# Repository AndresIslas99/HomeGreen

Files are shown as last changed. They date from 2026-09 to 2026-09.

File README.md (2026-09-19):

# HomeGreen — Huerto comercial automatizado en CDMX

**Guía-brújula, nivel wiki, para construir y operar un huerto comercial de microgreens y
hierbas NFT en un patio de 80 m² en la Ciudad de México**, automatizado con ESP32 + ESPHome +
Home Assistant, por fases y financiado con ventas. Todo lo que hay aquí es accionable: qué
comprar (con enlace y precio verificado), cómo instalarlo (con diagramas eléctricos,
hidráulicos y CAD), cómo operarlo (guías paso a paso), cómo validar cada avance (métodos
V1–V11 y gates), y el firmware listo para flashear.

> **Sitio web de la wiki:** https://andresislas99.github.io/HomeGreen/ — se publica solo desde
> `main` con GitHub Actions ([`.github/workflows/docs.yml`](.github/workflows/docs.yml)).
> La primera vez: *Settings → Pages → Source: GitHub Actions*. Para verla en local:
> `pip install mkdocs-material mkdocs-glightbox && mkdocs serve`.

## Empieza aquí (en este orden)

1. **[Antes de gastar un peso](docs/empieza-aqui/antes-de-gastar-un-peso.md)** — la semana 0:
   escritura/condominio, contador (¿eres socio de alguna empresa?), consumo eléctrico, tandeo y
   agua de tu llave, aviso de huerto, curso gratis. Cuesta $0–740 y evita los errores caros.
2. **[Cómo usar esta guía](docs/empieza-aqui/como-usar-esta-guia.md)** — convenciones, cómo
   marcar tu avance, cómo funcionan los gates.
3. **[Línea de tiempo](docs/empieza-aqui/linea-de-tiempo.md)** — 40 semanas con hitos, gates y
   calendario de riesgos climáticos.
4. **[Fase 0 · Validación comercial](docs/fases/fase-0/index.md)** — rack, 20 charolas, dos
   clientes recurrentes en 6 semanas. Si no se logra, perdiste ~$6k y comes microgreens.

## Mapa del proyecto

| Fase | Qué | Cuándo | Inversión (MXN) | Gate para pasar |
|---|---|---|---|---|
| [0 · Validación comercial](docs/fases/fase-0/index.md) | Rack bajo techo, microgreens, vender a chefs | Semanas 1–6 | $8,814 | ≥2 clientes con 3 compras semanales seguidas, margen ≥55 % |
| [1 · Túnel + automatización v1](docs/fases/fase-1/index.md) | Túnel PTR 3×6 m, tinaco + captación pluvial, nodo ESP32 de riego/ambiente | Meses 2–4 | $41,634 | 4–5 clientes fijos, demanda insatisfecha, v1 estable 30 días |
| [2 · NFT + automatización v2](docs/fases/fase-2/index.md) | Túnel 5×6 m, 8 líneas NFT, pH/EC, respaldo DC-first, cadena de frío | Meses 5–9 | $27,251 | Neto ≥$12k/mes × 3 meses con ≤9 h/semana medidas |
| [3 · Consolidación](docs/fases/fase-3/index.md) | Camas elevadas, gantry/visión, testbed agtech | Mes 10+ | discrecional | — |

> **Los montos salen de [`bom/partidas.csv`](bom/partidas.csv)** y los calcula
> [`tools/gen_bom.py`](tools/gen_bom.py), que falla si alguna fila no multiplica. El acumulado de
> las tres fases es **$77,699**, no los ~$86,500 que se publicaban antes: la diferencia es que el
> total viejo cobraba dos veces la partida de seguridad eléctrica y el no-break, y sumaba
> alternativas entre las que hay que elegir una. No se recortó nada del alcance; ver
> [BOM por fase](docs/referencia/bom.md).
>
> La Fase 1 sube y la Fase 2 baja porque el GFCI, la tierra física y el electricista ($4,559)
> estaban presupuestados en las dos, y el proyecto los exige en la S13 de la Fase 1.

## Qué contiene la wiki

| Sección | Para qué |
|---|---|
| [Fases](docs/fases/fase-0/index.md) | Por cada fase: compras exactas, montaje, operación, ventas y gate — con "cómo se verá" (planta + render 3D) |
| [Guías](docs/guias/sembrar-una-charola.md) | Una tarea = una página: sembrar, sanitizar semilla, armar línea NFT, calibrar sondas, instalar GFCI y tierra, flashear ESPHome, visitar a un chef, facturar, cobrar… |
| [Diseño](docs/diseno/index.md) | Arquitectura del sistema: [eléctrico](docs/diseno/electrico.md) (esquemas + pines), [hidráulico](docs/diseno/hidraulico.md) (P&ID), [control](docs/diseno/control.md) (lazos e histéresis), [datos](docs/diseno/datos.md), [layout del patio](docs/diseno/layout-patio.md), [estructura del túnel](docs/diseno/estructura-tunel.md) (CAD) |
| [Validación](docs/validacion/index.md) | Lazos L0–L4, métodos V1–V11 con checklists imprimibles, [KPIs](docs/validacion/kpis.md) y [gates](docs/validacion/gates.md) |
| [Software](docs/software/index.md) | [Firmware ESPHome](docs/software/firmware.md), [Home Assistant](docs/software/home-assistant.md) (automatizaciones y dashboard), [herramientas CLI](docs/software/herramientas-cli.md) |
| [Aprendizaje](docs/aprendizaje/videos.md) | Videos verificados (incrustados), libros y cursos por fase |
| [Referencia](docs/referencia/bom.md) | BOM por fase, normativa, clima, glosario, FAQ, [verificación de enlaces](docs/referencia/enlaces.md), los 9 documentos base y los 17 informes de investigación |

## Archivos que no son documentación

```
firmware/esphome/        nodo-riego-v1.yaml · nodo-ambiente.yaml · nodo-nft-v2.yaml (listos para ESPHome)
firmware/homeassistant/  automations.yaml · dashboard-huerto.yaml · configuration-snippets.yaml
hardware/electrico/      scripts schemdraw que generan los esquemas eléctricos (SVG)
hardware/cad/            modelos OpenSCAD paramétricos (túnel, rack, línea NFT, patio) + renders
hardware/hidraulico/     generador de diagramas P&ID
bom/                     listas de materiales por fase (CSV con enlace y estado del precio)
bitacora/                plantillas CSV (producción, ventas, cobranza, costos, timesheet) + datos de ejemplo
tools/                   check_links.py · kpis.py · informe_semanal.py · gate_audit.py (Python 3.11, sin dependencias)
.github/workflows/       docs.yml (publica la wiki) · links.yml (verifica enlaces cada lunes)
docs/assets/diagramas/   SVG eléctricos, hidráulicos, plantas, animaciones; PNG de CAD
```

## Los 6 números que cambiaron el plan original

1. La bomba periférica de 0.5 HP consumía ~324 kWh/mes → tarifa DAC (~$2,600/mes). Se rediseñó a
   **bomba 12 V DC colgada de una batería LiFePO4** (DC-first): ~32 kWh/mes y un apagón no mata el NFT.
2. **PVC sanitario** 4" ($415/tramo), no cédula 40 ($1,401): el NFT corre sin presión.
3. Precios de venta corregidos con mercado real: **charola viva $90–120**, clamshell $50–90/100 g.
4. **El chícharo con semilla a $340/kg pierde dinero** (275 g/charola): requiere arvejón de CEDA.
5. Racks reales cuestan **$2,000–2,600**; "Hunab" no existe (es Hanlob y no vende antigranizo).
6. **Neto realista $6,500–11,000/mes** con merma, enero −35 %, CAC recurrente y 15 h/semana reales.
7. **UNIT Electronics tiene mostrador en Av. Copilco 357, Coyoacán** — el resto de la wiki lo
   trataba como proveedor solo en línea. Cubre casi todo el BOM de automatización, y ahí el
   sensor SHT41 cuesta **$91** contra los $300 del SHT31 que traía el BOM. La ruta de compra
   presencial completa está en [Proveedores presenciales](docs/referencia/proveedores-presenciales.md).

## Filosofía

1. **Vender antes de construir** — cada fase se financia con la anterior; los gates se escriben
   y se versionan antes de gastar.
2. **Fail-safe físico, no de software** — la bomba NFT cuelga del bus de batería; Home Assistant
   avisa y optimiza, pero el agua nunca depende de que esté vivo.
3. **Todo desde el tinaco, nunca de la toma** — CDMX tiene tandeo.
4. **Operación como sistema de control** — todo se mide y se registra; un lazo agéntico semanal
   (LLM sobre la bitácora y Home Assistant) convierte los datos en decisiones.

## Contribuir

Los precios caducan: si encuentras uno distinto, corrige la fila en `bom/*.csv` o en
`docs/referencia/01-proveedores-cdmx.md` con la fecha y abre un PR.

Dos comprobaciones corren solas y conviene correrlas antes de abrir el PR:

```bash
mkdocs build --strict        # falla con cualquier enlace interno, ancla o imagen rota
python3 tools/check_links.py # verifica los ~680 enlaces externos
```

`--strict` valida las 112 páginas: enlaces relativos, anclas, imágenes y que no haya páginas
fuera del `nav`. `check_links.py` corre cada lunes (workflow `links.yml`) y **solo falla con un
enlace muerto nuevo**: los ya conocidos y anotados viven en
[`tools/enlaces-muertos-conocidos.txt`](tools/enlaces-muertos-conocidos.txt), así un `dead`
nuevo —una partida del BOM que ya no se puede comprar— no se pierde entre el ruido viejo.

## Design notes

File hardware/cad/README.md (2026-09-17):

# Modelos CAD paramétricos (OpenSCAD)

Modelos 3D del huerto en OpenSCAD (software libre; probados con la versión 2021.01).
Cada archivo es un modelo paramétrico: cambias un número al principio del archivo, vuelves a
renderizar y el PNG de la wiki se actualiza. Los renders viven en
`docs/assets/diagramas/cad/` y los usan las páginas de diseño
(`docs/diseno/estructura-tunel.md`, `rack-y-charolas.md`, `layout-patio.md`) y los índices
de fase.

| Archivo | Qué modela | Render (docs/assets/diagramas/cad/) | Fase |
|---|---|---|---|
| `tunel_3x6.scad` | Túnel a dos aguas 3 × 6 m: PTR 1½" cal. 14, 6 columnas, placas base 100 × 100 mm con 4 anclas 3/8" × 5", pendiente 30 %, largueros, contravientos, plástico translúcido, malla antigranizo a 150 mm, canalón + bajante. Imprime la **lista de cortes** en consola. | `tunel-3x6.png` | 1 |
| `tunel_5x6.scad` | El mismo módulo `tunel()` con `ancho = 5000`, 4 pórticos (8 columnas) y 2 largueros de techo por agua. No copia geometría: hace `use <tunel_3x6.scad>`. | `tunel-5x6.png` | 2 |
| `rack_charolas.scad` | Rack Husky 1830 × 914 × 457 mm, 5 niveles, 3 charolas 1020 (254 × 508 × 60 mm) por nivel, 2 tubos T8 de 1200 mm por nivel iluminado, riser de riego. Los niveles muestran los estados del SOP (tapada / brote / desarrollo / cosecha). | `rack-charolas.png` | 0–1 |
| `linea_nft.scad` | Línea NFT: PVC sanitario 4" (OD 114 mm) × 3000 mm, 10 perforaciones a 200 mm entre centros, canastillas 3", pendiente 2.5 %, 3 soportes de PTR 1", tapas, entrada ½" y retorno 2". Incluye el módulo `bancada_nft()` (n líneas sobre soportes compartidos). | `linea-nft.png` | 2 |
| `patio_fase2.scad` | Composición del patio de 10 × 8 m (supuesto): túnel 5 × 6, 8 líneas NFT en 2 bancadas, tambo 200 L, tinaco 750 L, 3 racks, gabinetes IP65, zona de cosecha. Usa los tres archivos anteriores con `use <...>`. | `patio-fase-2-3d.png` | 2 |

Unidades: **milímetros**. Ejes: X = oeste → este, Y = sur → norte, Z = altura. En el túnel la
cumbrera corre a lo largo de Y y la puerta va en la cabecera norte (`y = largo`), porque la
wiki supone el acceso del patio al norte.

## Requisitos

- OpenSCAD 2021.01 o posterior (`sudo apt install openscad` en Debian/Ubuntu; en macOS `brew
  install --cask openscad`; en Windows el instalador oficial).
- Para renderizar sin pantalla (servidor, CI): `xvfb-run` (`sudo apt install xvfb`).
- Fuente DejaVu Sans para los rótulos (viene en casi todas las distribuciones; si falta, el
  rótulo sale con la fuente por defecto y no pasa nada).

## Cómo modificar parámetros

1. Abre el `.scad` en el editor de OpenSCAD (o cualquier editor de texto).
2. Todos los parámetros están **al principio del archivo**, agrupados y comentados en español
   (geometría, perfiles, placa y anclas, cubierta, canalón, "qué dibujar", colores).
3. Cambia el valor, guarda y pulsa F5 (preview). La consola imprime la lista de cortes / el
   resumen con los nuevos valores.

Ejemplos útiles:

| Quiero… | Cambia… |
|---|---|
| Un túnel de 4 × 7 m | En `tunel_3x6.scad`: `ancho = 4000; largo = 7000;` (o crea un `tunel_4x7.scad` con `use <tunel_3x6.scad>` como hace `tunel_5x6.scad`). |
| Postes cada 2 m en vez de 3 m | `n_porticos = 4` (8 columnas, 32 anclas). |
| Alero a 2.2 m | `h_columna = 2200`. |
| Pendiente de 25 % (mínimo) | `pendiente = 25`. No bajes de 25 %: el granizo acumulado es la causa #1 de colapso del plástico. |
| Malla antigranizo a 100 mm del plástico | `sep_malla = 100` (el informe admite 10–20 cm). |
| Ver solo el esqueleto (sin plástico ni malla) | `mostrar_plastico = false; mostrar_malla = false;` |
| Bajante del canalón en el alero oeste | `lado_bajante = -1`. |
| Cortinas laterales dibujadas abiertas | Hoy se dibujan cerradas; pon `mostrar_plastico = false` o edita la altura del `cube` de "cortinas laterales" en `tunel()`. |
| Rack de 1.22 m de ancho (Husky ancho) | En `rack_charolas.scad`: `rack_ancho = 1219; rack_fondo = 610; charolas_por_nivel = 4;` |
| Charolas 1020 sin sobresalir del fondo | Solo con el rack de 610 mm de fondo (arriba); con 457 mm la charola de 508 sobresale 25 mm por lado, es normal. |
| Cilantro a 15 cm en el NFT | En `linea_nft.scad`: `sep_perf = 150; n_plantas = 14;` (14 × 150 = 2.1 m centrados en 3 m). |
| Perforación para la canastilla que compré | `d_perf = <lo que mediste en el cuerpo bajo el labio>` y `canastilla_cuerpo` igual. **El diámetro real se mide en la canastilla, nunca se toma de aquí.** |
| Pendiente NFT de 3 % | `pendiente = 3` (en `linea_nft.scad`). |
| Bancada de 3 líneas | En `patio_fase2.scad`: `nft_lineas_por_bancada = 3`. |
| Patio de 12 × 7 m | En `patio_fase2.scad`: `patio_x = 12000; patio_y = 7000;` y reacomoda `tunel_cx`, `tunel_y0`, `tinaco_pos`, `racks`. |

Las funciones y módulos se reutilizan entre archivos con `use <archivo.scad>`; `use` importa
módulos y funciones (con sus valores por defecto) pero **no** las variables de nivel superior:
por eso `tunel_5x6.scad` vuelve a declarar `ancho`, `largo`, etc. y los pasa como argumentos.

## Cómo re-renderizar los PNG de la wiki

Desde `hardware/cad/` (las rutas de salida son relativas a esa carpeta). Con pantalla, quita
`xvfb-run -a`.

```bash
cd hardware/cad
OUT=../../docs/assets/diagramas/cad
OPTS="--autocenter --viewall --imgsize=1400,1000 --projection=p --colorscheme=Tomorrow"

xvfb-run -a openscad -o $OUT/tunel-3x6.png       $OPTS --camera=0,0,0,62,0,212,0 tunel_3x6.scad
xvfb-run -a openscad -o $OUT/tunel-5x6.png       $OPTS --camera=0,0,0,62,0,212,0 tunel_5x6.scad
xvfb-run -a openscad -o $OUT/rack-charolas.png   $OPTS --camera=0,0,0,72,0,22,0  rack_charolas.scad
xvfb-run -a openscad -o $OUT/linea-nft.png       $OPTS --camera=0,0,0,52,0,25,0  linea_nft.scad
xvfb-run -a openscad -o $OUT/patio-fase-2-3d.png $OPTS --camera=0,0,0,42,0,200,0 patio_fase2.scad
```

- `--camera=tx,ty,tz,rx,ry,rz,dist` es la cámara "gimbal": con `--viewall` la distancia se
  ajusta sola y solo importan `rx` (elevación: 90 = de frente, 0 = desde arriba) y `rz`
  (azimut: 0 = desde el sur, 180–215 = desde el norte/noreste, donde está la puerta).
- Si un render sale vacío o cortado, cambia `rz`/`rx` o sube `dist` quitando `--viewall`.
- Cada PNG de la wiki pesa entre 48 y 230 KB; si uno sale de menos de 20 KB, el modelo no se
  dibujó (revisa errores de sintaxis en la consola: `openscad -o x.png archivo.scad 2>&1`).
- Los `ECHO` (lista de cortes, resumen de rack/línea) salen por **stdout**: para guardarlos,
  `openscad -o /tmp/x.png tunel_3x6.scad > cortes.txt 2>&1`.

## Cómo leer la lista de cortes del túnel

`tunel_3x6.scad` y `tunel_5x6.scad` imprimen tres bloques:

1. `PERFIL | pieza | cantidad × longitud` (longitudes de eje a eje; los cabios llevan un
   perfil extra de traslape).
2. Metros lineales por perfil y el **mínimo teórico** de tramos (metros ÷ 6), que **no**
   incluye el desperdicio de corte.
3. Los **tramos reales** que hay que comprar: el modelo empaqueta las piezas en tramos por
   *primer ajuste decreciente* (FFD) con 3 mm de kerf por corte, y lo imprime para tramos
   de 6.00 m y de 6.10 m (el PTR llega en 6.0–6.10 m según el proveedor), con el detalle
   de qué piezas salen de cada tramo. Ejemplo (túnel 3 × 6 m):

   ```
   ECHO: "PTR 1 1/2: tramos REALES de 6 m (FFD, kerf 3 mm): 11 -> [[6000], [6000], [6000], [2924, 2924], [2924, 2450, 412], [2000, 2000, 1586], ...]"
   ECHO: "PTR 1 1/2: tramos REALES de 6.1 m (FFD, kerf 3 mm): 10 -> ..."
   ```

   Es una cota práctica y reproducible, no la óptima: dásela al herrero como punto de
   partida. Truco: tres columnas de 2.00 m no caben en un tramo de 6.00 m exactos
   (6,000 + 2 cortes); si tu proveedor entrega 6.10 m sí caben, y si no, corta las columnas
   a 1.99 m. Para otro largo de tramo o de kerf: `lista_cortes(L_tramo = 6100, kerf = 2)`.
   La función `empaquetar(longitudes, L_tramo, kerf)` sirve para cualquier lista de cortes
   (p. ej. los soportes de PTR 1" del NFT).

## Exportar a STL / DXF (opcional)

```bash
openscad -o tunel_3x6.stl tunel_3x6.scad   # malla 3D (los .stl están en .gitignore)
openscad -o placa.dxf placa_2d.scad         # plano 2D: solo si creas un archivo con projection()
```

Para planos 2D de las placas base o de las perforaciones del NFT, lo más simple es un archivo
nuevo con `projection()` sobre el módulo que quieras y exportar a DXF/SVG.

## Limitaciones honestas

- Es un modelo **geométrico** para dimensionar, cortar y explicar; **no es un cálculo
  estructural**. Las cargas de viento y el margen de las anclas se discuten con cifras del
  informe en `docs/diseno/estructura-tunel.md`; para una estructura mayor de 30 m² o en azotea,
  consulta a un ingeniero.
- Las uniones se dibujan a tope (sin cartabones ni cordones de soldadura); el herrero decide
  el detalle de unión y puede pedir 1–2 cm extra por pieza para escuadrar.
- En el preview (F5/OpenCSG) lo que se dibuja después de una superficie translúcida queda
  oculto tras ella: por eso en `patio_fase2.scad` el túnel y las bardas van al final. Si
  agregas objetos dentro del túnel, agrégalos **antes** del bloque "Superficies translúcidas".
- Las dimensiones del tinaco de 750 L y del tambo de 200 L son típicas, no de ficha técnica:
  mide el que compres antes de trazar bases.

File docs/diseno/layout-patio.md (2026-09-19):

# Layout del patio por fase

**En una línea:** dónde va cada cosa en los 80 m² —racks, túnel, tinaco, tambo NFT, gabinetes, cuarto de cosecha, camas— y por dónde corren el agua y la electricidad, fase por fase, para que replantees el patio real en una mañana con hilo, cinta y escuadra.

!!! info "Qué decide esta página"
    - **La posición de cada elemento** en las cuatro plantas (Fase 0 → 3) y **qué cambia** de una fase a la siguiente sin tirar nada.
    - **Los recorridos** de agua (red, captación, riego, llenado, drenaje) y eléctricos (127 V, 12 V, señal) con su longitud sobre el supuesto: son los metros de cable, manguera y canalón que compras.
    - **Las distancias mínimas** (pasillos, separaciones, paso libre) que deben sobrevivir cuando tu patio no mida 10 × 8 m.
    - Cómo **adaptar** el plano a otro patio y el **checklist de replanteo** antes de perforar la losa.
    - Las plantas se generan con `hardware/cad/layout.py` (Python estándar, sin dependencias): cambia las constantes de la sección `GEOMETRIA` y regenera con `python3 hardware/cad/layout.py`. Escala 1:50 (1 m = 100 px), norte arriba, cotas en m.

!!! warning "Todo el patio del dibujo es un SUPUESTO"
    Patio de **10 × 8 m (80 m²), casa al sur, zaguán de 1.0 m al norte, coladera en la esquina noreste, losa de concreto, cobertizo existente de 3.5 × 1.7 m en la esquina sureste**. No conocemos tu predio. Lo que sí es diseño (y no supuesto) son las reglas de la sección [7. Distancias mínimas](#7-distancias-minimas-que-deben-sobrevivir-a-cualquier-patio): si las respetas, la forma exacta importa poco.

## 1. Cómo leer las plantas

- **Colores por sistema:** azul = agua (línea continua a presión, discontinua drenaje/purga, raya-punto canalón y bajante); ámbar = eléctrico (continua 127 V, discontinua 12 V CC, punteada señal/Wi-Fi); verde = cultivo (racks, bancadas NFT, camas); gris rayado = techos (túnel y cobertizo); gris discontinuo = reserva de una fase posterior.
- **Notas clave:** los círculos numerados del plano se explican en el bloque desplegable *«Leyenda y notas clave del plano»* que va debajo de cada imagen (también en las páginas de cada fase). Ese texto lo genera `hardware/cad/layout.py` en `docs/assets/diagramas/layout/<plano>.notas.md`: está fuera del dibujo a propósito, para leerlo a tamaño de lectura, buscarlo y copiarlo. Aquí abajo se repiten las decisiones, no el texto completo.
- **Tags de instrumentos** (TK-1, P-1, SV-1, LT-1, AT-1…) son los mismos de [hidraulico.md](hidraulico.md) y [electrico.md](electrico.md); los gabinetes son **GAB-A** (127 V CA), **GAB-1** (nodo de riego, CC), **GAB-2** (nodo NFT, CC), **GAB-DC** (batería y fusiblera) y **GAB-3** (gantry, Fase 3).
- **Orientación del túnel:** cumbrera este–oeste, puerta de 0.9 m en la cabecera **este** (de frente al zaguán y al tinaco), canalones en los aleros norte y sur con bajante en la esquina noreste. El render 3D `patio-fase-2-3d.png` de [estructura-tunel.md §8](estructura-tunel.md) tiene el túnel girado 90° (cumbrera norte–sur, puerta al norte): es un boceto de volumen; **manda esta planta**. Para que coincidan, en `hardware/cad/patio_fase2.scad` gira el túnel y cambia `tunel_cx`, `tunel_y0` y `tinaco_pos`.

## 2. Fase 0 — un rack bajo techo

Planta del patio en Fase 0: rack Husky bajo el cobertizo junto a la casa, mesa de siembra junto a la toma de agua, reserva del túnel de Fase 1 trazada en el piso

??? note "Leyenda y notas clave del plano"

    --8<-- "assets/diagramas/layout/patio-fase-0.notas.md"

**Qué hay:** 1 rack Husky de 5 niveles (183 × 91 × 46 cm, $2,019 verificado, [BOM Fase 0](../referencia/bom.md)) pegado a la pared sur bajo el cobertizo, una mesa de siembra de 1.2 × 0.6 m junto a la toma de agua (1.6 m; el requisito es < 10 m), cubeta de remojo/tina, cubeta con tapa para sustrato usado en la esquina opuesta y el contacto existente (sin GFCI todavía). Nada más: la Fase 0 valida que los chefs **pagan** ([00-plan-maestro](../referencia/00-plan-maestro.md)).

**Por qué ahí:** el rack quiere luz indirecta, sin sol de mediodía (a 2,240 msnm el UV quema los brotes) y sin goteo; el cobertizo junto a la casa cumple las tres, tiene el contacto a 20 cm y la toma a < 2 m ([03-instalacion §0.1](../referencia/03-instalacion.md)).

**Qué haces con el resto del patio:** trazar con hilo y escuadra 3-4-5 la reserva del túnel de 3 × 6 m (a 0.6 m de las bardas oeste y 0.8 m de la norte) y medir ahí, durante 3 días, temperatura mín/máx (ideal 16–24 °C) y luz con la app Photone (100–200 µmol/m²s). No dejes nada pesado sobre la reserva ni sobre la futura base del tinaco.

## 3. Fase 1 — túnel 3 × 6, tinaco, gabinetes y GFCI

Planta del patio en Fase 1: túnel de 6 × 3 m con 3 racks, tinaco de 750 L en la esquina noreste con tlaloque, gabinetes GAB-A y GAB-1, troncal eléctrica aérea desde el cobertizo, drenaje a la coladera y cuarto de cosecha

??? note "Leyenda y notas clave del plano"

    --8<-- "assets/diagramas/layout/patio-fase-1.notas.md"

**Qué cambia respecto a Fase 0:**

| Elemento | Dónde | Por qué ahí |
|---|---|---|
| Túnel 6 × 3 m (18 m²), 3 pórticos a 3 m, placa + 4 anclas de cuña 3/8" × 5" por columna | x 0.6–6.6, y 0.8–3.8 (0.6 m a la barda oeste, 0.8 m a la norte) | Deja 4.2 m libres hacia la casa para crecer 2 m en Fase 2 y para el paso; 0.6 m perimetrales para tensar plástico y drenar ([instalacion-tunel-detalle §2](../research/instalacion-tunel-detalle.md)) |
| Puerta 0.9 m en la cabecera este | y 1.9–2.8, abre hacia afuera | De frente al zaguán y al tinaco; el paso túnel–tinaco queda en 0.9 m |
| 3 racks Husky en fila | pared norte interior, x 2.4 / 3.65 / 4.9, separados 0.34 m | Los T8 de 120 cm vuelan 14 cm por lado; el rack 3 es el testigo con los 4 capacitivos y queda a ≤ 1.5 m de GAB-1 |
| Mesa de siembra 1.2 × 0.6 (+ tapete térmico dic–feb) | pared norte, oeste de los racks | Misma fila de trabajo; en Fase 2 su lugar lo puede tomar el rack 4 |
| Extractor | cabecera oeste, a 1.8 m | Tiro cruzado: entra aire por la puerta y los faldones, sale por el oeste |
| TK-1 tinaco 750 L sobre base firme 1.3 × 1.3 m | esquina NE, a 0.4 m de la coladera y 0.9 m del túnel | Lleno pesa ~750 kg: al piso, nunca sobre estructura; rebosadero corto a la coladera; base sombreada por la barda |
| SP-1 tlaloque + filtro de hojas | colgado del tramo de 3" a 2 m, junto al tinaco | El canalón norte baja en la esquina NE y cruza el paso **por arriba** (2 m); el canalón sur baja en la SE y sube por la cabecera este en un colector de 2" |
| P-1 (diafragma 12 V + presostato) + F-1 sedimentos | caja IP65 junto a la salida inferior del tinaco | Succión corta; la línea de riego ½" sube a 2 m, entra por la cabecera este sobre el dintel y corre por el larguero norte con un riser por rack |
| GAB-1 (nodo de riego, CC) | columna NE interior, a 2.0 m | ≤ 1.5 m del rack testigo (capacitivos: regla práctica 3 m), ≤ 2 m del tinaco (LT-1, TT-1) y de P-1; Wi-Fi a ~7 m del cerebro con una pared |
| GAB-A (127 V CA: fuente 12 V 5 A + contactor K5 de T8/extractor) | pared de la casa bajo el cobertizo, a 1.5 m | Cordón de uso rudo de 1 m al contacto WR in-use; bajo techo; en Fase 2 recibe el cargador |
| Troncal aérea a 2.2 m con mensajero de acero | cobertizo → columna SE → cabecera este → GAB-1 | 127 V (T8/extractor), 12 V (GAB-1) y señal K5 en un solo tendido; nunca cruza un pasillo a nivel de piso |
| Breaker QO120GFI 20 A + conduit 12 AWG + contacto WR + varilla copperweld 5/8" × 3 m | centro de carga y pared de la casa | Obligatorio antes del primer relé: el patio es "lugar mojado" ([electrico.md §4](electrico.md)) |
| Cuarto de cosecha (mesa inox, tina + lavamanos, hielera, cortina) | cobertizo | La mesa de siembra de Fase 0 se vuelve mesa de cosecha; corte separado del cultivo por cortina (NOM-251) |
| Tambo de composta | esquina SO | Lejos del cultivo y de la cosecha; 100–150 kg/mes de coco con raíces ([07 §12](../referencia/07-puntos-ciegos-y-riesgos.md)) |

**Drenaje (la decisión menos obvia):** las charolas colectoras de los 3 racks descargan a una manguera de 2" a nivel de piso que corre por la pared norte, baja por la cabecera este, sale del túnel en y = 3.1 m (al sur de la puerta), sigue por la barda este y llega a la coladera: **≈ 12.4 m con pendiente ≥ 1 %**. Para tener esa pendiente los racks van sobre bloques de 15 cm. Así ningún drenaje cruza el paso zaguán → puerta del túnel. Si en tu patio el recorrido pasa de ~12 m, usa tubo PVC sanitario de 2" en vez de manguera o drena a una cubeta con flotador [POR VERIFICAR: caudal real de drenaje de 3 racks; medirlo la primera semana con la charola colectora y una cubeta graduada].

## 4. Fase 2 — túnel 5 × 6, NFT, DC-first y cuarto de cosecha completo

Planta del patio en Fase 2: túnel ampliado a 6 × 5 m con 3 racks y dos bancadas de 4 líneas NFT, tambo de 200 L, bombas de 12 V, GAB-2, GAB-DC con batería bajo el cobertizo, refrigerador y ESP32-CAM

??? note "Leyenda y notas clave del plano"

    --8<-- "assets/diagramas/layout/patio-fase-2.notas.md"

**Qué cambia respecto a Fase 1:**

| Elemento | Dónde | Por qué ahí |
|---|---|---|
| Fachada sur del túnel movida 2 m: 6 × 5 m = 30 m², 4 pórticos a 2 m | y 0.8–5.8; 2.2 m libres hasta la casa | Las bases de las columnas este/oeste se reutilizan; el canalón sur se cuelga en el alero nuevo; la bajante NE, el tinaco, GAB-1 y la troncal **no se mueven** |
| 2 bancadas NFT E–O de 4 líneas PVC sanitario 4" × 3 m | A: y 2.4–3.52 · B: y 4.42–5.54; x 1.2–4.2 | Alto al **oeste** (manifold ¾" con 8 válvulas) y bajo al **este** (retornos 2"), pendiente 2–3 %; pasillo de 0.9 m entre bancadas y 0.94 m frente a los racks; la A se atiende por dos lados, la B por uno |
| TK-2 tambo 200 L tapado + P-1/P-2 diafragma 12 V + F-1 malla 120 + FT-1 | entre los dos retornos, este de las bancadas | Retorno por gravedad; succión corta; sondas AT-1/AT-2/TT-2 en el retorno; peristálticas DP-1/2/3 dosifican al tambo junto a la succión ([03 §2.2](../referencia/03-instalacion.md)) |
| Subida ¾" bombas → manifold | al pie de la bancada A, por el piso pegada al tubo | No cruza pasillo; ≈ 4.4 m |
| Llenado: tinaco → F-2 dúplex sedimento + carbón → SV-1 NC → tambo | caja F-2 junto a P-1; entra al túnel por la cabecera este en y = 2.95 m | Quita el cloro de red antes del NFT; ≈ 4.5 m |
| Purga SV-2 (cambio cada 2–3 semanas, 200 L) | del tambo al drenaje de Fase 1 | Se une al colector de 2" dentro del túnel; ≈ 8.8 m a la coladera |
| GAB-2 (nodo NFT, CC) | columna sur en x = 4.6, a 1.5 m | 1.6 m a las sondas del retorno, 1.7 m a las bombas, 0.6 m del bus 12 V |
| GAB-DC (LiFePO4 100 Ah + EPEVER LS2024B + fusiblera) | pared de la casa bajo el cobertizo, batería a 30 cm del piso, caja separada de GAB-A | Bajo techo, cerca del cargador (GAB-A) y del contacto GFCI; bus 12 V por la troncal aérea: ≈ 4.2 m a las bombas (14 AWG cumple ≤ 3 % hasta 4 m; con 12 AWG hasta 6 m, [electrico.md §6](electrico.md)) |
| Panel 100 W (opcional) | azotea de la casa | Nunca sobre el plástico del túnel |
| Refrigerador usado 9–11 ft³ a 4–5 °C | cobertizo, contacto GFCI propio | El cortado a 20–25 °C dura < 1 día ([07 §3](../referencia/07-puntos-ciegos-y-riesgos.md)) |
| Mesa de germinación (foami) y trasplante | este del túnel, junto a la puerta y al tambo | Trasplante a canastilla sin cruzar el túnel |
| ESP32-CAM | columna NE, a 2 m | Ve puerta, zaguán y tinaco: detección nocturna ([07 §10](../referencia/07-puntos-ciegos-y-riesgos.md)) |
| Rack 4 (opcional) | donde estaba la mesa de siembra | La siembra pasa a la mesa del cobertizo |

!!! tip "Separación entre líneas NFT"
    El plano usa **28 cm eje a eje** (bancada de 1.12 m). Con albahaca de porte grande a 20 cm entre canastillas puede hacer falta 30–35 cm: la bancada sube a 1.2–1.4 m y el pasillo central baja a 0.7 m. Decide con la primera cosecha [POR VERIFICAR: ancho de dosel de albahaca Nufar/Genovese a 4–5 semanas en tu túnel].

## 5. Fase 3 — camas elevadas, goteo, gantry y cámara

Planta del patio en Fase 3: Fase 2 más tres camas elevadas con goteo desde el tinaco, gantry XY sobre la cama sur, GAB-3 y cámara fija en poste

??? note "Leyenda y notas clave del plano"

    --8<-- "assets/diagramas/layout/patio-fase-3.notas.md"

**Qué cambia respecto a Fase 2:** tres camas elevadas (alt. 0.7–0.9 m [POR VERIFICAR: material y altura no están en la fuente de verdad]) —dos de 1.0 × 2.8 m en la franja este, sobre la línea de drenaje, y una de 3.1 × 1.0 m al sur del túnel—, goteo colgado de HA desde el tinaco (SV-3 de 12 V NC en la caja F-2; ramal este ≈ 3.8 m y ramal sur por la troncal y el alero sur ≈ 6.5 m), gantry XY tipo FarmBot sobre la cama 3 (rieles V-slot en los bordes largos, carrera ≈ 3.0 × 0.9 m), GAB-3 con el driver en la pared de la casa y una cámara fija en poste de 2 m. La composta del tambo alimenta las camas sin cruzar el cuarto de cosecha.

**Sobre la meta de 15–20 m² de camas:** en este supuesto caben **8.7 m²** respetando pasillos ≥ 0.7 m, camas de ≤ 1.0 m atendidas por un lado y el paso al reparto. Para llegar a 15–20 m² tienes tres caminos, en orden de sensatez:

1. **No ampliar el túnel a 5 × 6** (quedarte en 3 × 6 con 3 racks + 4 líneas NFT): libera 12 m² al sur donde caben dos camas de 1.2 × 5 m atendidas por ambos lados (12 m²) → total ~20 m². Es la opción si la Fase 3 te importa más que la segunda bancada NFT.
2. **Camas en la azotea de la casa** (goteo desde el tinaco con la presurizadora de ¼ HP, [research/agua-captacion](../research/agua-captacion.md)): no compite con el negocio por el piso. [POR VERIFICAR: carga admisible de la losa de azotea; una cama de 1 × 3 m con 30 cm de sustrato húmedo pesa ~700 kg].
3. **Camas de dos niveles** (escalonadas contra la barda este): dobla la superficie de la franja este sin quitar pasillos, a costa de altura y de que el gantry solo cubra la cama baja.

Regla de oro de Fase 3: **ningún cable ni manguera nueva cruza pasillos a nivel de piso**; todo aéreo a 2 m o pegado a barda/cama. Nada de esto es el negocio: solo si Fases 1–2 se pagan ([00-plan-maestro §Fase 3](../referencia/00-plan-maestro.md)).

## 6. Recorridos de agua y eléctricos (metros sobre el supuesto)

Son las longitudes que compras (más 10–15 % de desperdicio y subidas/bajadas). Cambian si cambias la geometría; el script las recalcula e imprime en cada plano.

=== "Agua"

    | Recorrido | Trayecto | Longitud | Material | Fase |
    |---|---|---|---|---|
    | Red SACMEX → FV-1 flotador | toma en la pared de la casa → barda este (aéreo 1.5 m) → tinaco | ≈ 7.6 m | tubo/manguera ½" reforzada; solo rellena el tinaco, nunca alimenta riego directo | 1 |
    | Canalón norte y sur | aleros del túnel, pendiente 0.5–1 % hacia el este | 6 + 6 m (2 tramos de 3.07 m por alero, $269 c/u) | canalón PVC doméstico ([instalacion-tunel-detalle §4](../research/instalacion-tunel-detalle.md)) | 1 |
    | Bajante SE → colector → bajante NE → tlaloque → tinaco | cabecera este a 2 m + tramo horizontal sobre el paso | 3 m (F1) / 5 m (F2) + 1.3 m | PVC 2"–3" | 1 |
    | Rebosadero TK-1 → coladera | esquina NE | ≈ 1 m | manguera 1" | 1 |
    | Riego P-1 → risers de los racks | junto al tinaco → cabecera este (sobre el dintel) → larguero norte → 3 risers | ≈ 6.6 m + 3 × 2 m | manguera ½" del kit de nebulizadores | 1 |
    | Drenaje racks → coladera | pared norte → cabecera este → sale en y = 3.1 → barda este → coladera | ≈ 12.4 m, pendiente ≥ 1 % | manguera o PVC sanitario 2" | 1 |
    | Llenado tinaco → F-2 → SV-1 → TK-2 | caja F-2 → cabecera este (y = 2.95) → tambo | ≈ 4.5 m | tubo ½" | 2 |
    | Subida bombas → manifold | pie de la bancada A | ≈ 4.4 m | PVC/manguera ¾" | 2 |
    | Manifold + retornos | oeste / este de las bancadas | 3.2 m + 2 × 1.6 m | ¾" con 8 válvulas / sanitario 2" | 2 |
    | Purga SV-2 → coladera | tambo → colector de drenaje | ≈ 8.8 m | sanitario 2" | 2 |
    | Goteo camas (SV-3) | ramal este / ramal sur por la troncal y el alero sur | ≈ 3.8 m / ≈ 6.5 m | manguera ½" + cinta de goteo | 3 |

=== "Eléctrico"

    | Recorrido | Trayecto | Longitud | Conductor (ver [electrico.md §6](electrico.md)) | Fase |
    |---|---|---|---|---|
    | Centro de carga → contacto WR in-use | dentro de la casa, conduit | ≈ 1.5–3 m [POR VERIFICAR en sitio] | 12 AWG THW-LS ×3 en conduit; breaker QO120GFI | 1 |
    | Contacto WR → GAB-A | pared del cobertizo | 1 m | cordón SJT 3 × 14 AWG uso rudo | 1 |
    | Troncal aérea GAB-A → mástil → columna SE → cabecera este → GAB-1 | a 2.2 m con mensajero de acero | ≈ 6.6 m (igual en F1 y F2) | 127 V: 14 AWG (T8 + extractor, K5) · 12 V 5 A: 10–12 AWG por caída ≤ 3 % · señal K5: 18 AWG | 1 |
    | 127 V larguero norte → T8 de cada rack y extractor | dentro del túnel, a 2 m | ≈ 6.9 m + 3 bajadas | 14 AWG en canaleta, tierra al chasis del rack | 1 |
    | 12 V GAB-1 → P-1 | cabecera este a 2 m → caja P-1 | ≈ 2.5 m | 14 AWG | 1 |
    | Sensores → GAB-1 | MT-1…4 (rack 3), SHT31 (centro), LT-1/TT-1 (tinaco) | 1.5 / 2.5 / 2 m | 22–24 AWG blindado; conector capacitivo hacia arriba | 1 |
    | Wi-Fi cerebro → GAB-1 / GAB-2 | una pared | ≈ 7 m | — (si hay pérdida de paquetes, repetidor en la ventana) | 1 |
    | Bus 12 V GAB-DC → bombas NFT / → GAB-2 | troncal aérea → pared sur | ≈ 4.2 m / ≈ 3.1 m | 12 AWG (F1/F2 10 A en fusiblera) | 2 |
    | Sondas AT-1/AT-2/TT-2 → GAB-2 | retorno → columna sur | ≈ 1.6 m | cable BNC de la sonda [POR VERIFICAR: largo del cable de la sonda comprada] | 2 |
    | GAB-DC → GAB-3 (gantry) | pared de la casa, aéreo sobre la puerta | ≈ 2.3 m | 14 AWG | 3 |

!!! danger "Lo que no negocia ningún patio"
    Todo lo de 127 V en el patio cuelga de **un** breaker GFCI, va en conduit o cordón de uso rudo, entra a gabinetes IP65 por prensaestopas y tiene tierra física medida ≤ 25 Ω. 127 V y 12 V nunca comparten gabinete. Los cruces de pasillos son **aéreos a ≥ 2 m**, nunca por el piso ([electrico.md §4](electrico.md), [research/electrico-respaldo-seguridad §3.6](../research/electrico-respaldo-seguridad.md)).

## 7. Distancias mínimas que deben sobrevivir a cualquier patio

| Regla | Valor | De dónde sale |
|---|---|---|
| Túnel a bardas laterales / a la barda norte | ≥ 0.6 m / ≥ 0.8 m | Espacio para tensar plástico, canalón y drenaje perimetral ([03 §1.1](../referencia/03-instalacion.md)) |
| Anclas a bordes o grietas de la losa | ≥ 15 cm; losa sana ≥ 10 cm | [instalacion-tunel-detalle §1](../research/instalacion-tunel-detalle.md) |
| Pasillos de trabajo (racks, bancadas, cosecha) | ≥ 0.9 m; entre camas ≥ 0.7 m | Carrito de charolas y dos personas de frente; regla práctica del diseño |
| Bancada NFT atendida por un solo lado | ≤ 1.2 m de ancho | Alcance de brazo; la bancada B del plano mide 1.12 m |
| Separación entre racks en fila | ≥ 0.30 m (plano: 0.34 m) | Los T8 de 120 cm vuelan 14.3 cm por lado del rack de 91.4 cm |
| Paso libre túnel–tinaco / puerta del túnel | ≥ 0.9 m | Una persona con charola; puerta de 0.9 m ([estructura-tunel.md](estructura-tunel.md)) |
| Tinaco | al piso sobre base firme; rebosadero a ≤ 1 m de la coladera; sin tapar la coladera; opaco o a la sombra | 750 kg lleno ([03 §1.2](../referencia/03-instalacion.md)); algas ([research/agua-captacion](../research/agua-captacion.md)) |
| Toma de agua al punto de siembra | < 10 m | [03 §0.1](../referencia/03-instalacion.md) |
| Rack | bajo techo, sin sol de mediodía ni goteo; nivelado; sobre bloques de 15 cm si drena por manguera | [03 §0.2](../referencia/03-instalacion.md) |
| Sensores capacitivos → GAB-1 | ≤ 3 m | Señal analógica ([electrico.md §6](electrico.md)) |
| Gabinetes | a ≥ 1.2 m del piso; GAB-A (CA) y GAB-1/GAB-2/GAB-DC (CC) separados; batería a ≥ 30 cm del piso, bajo techo | [electrico.md §1](electrico.md) |
| Cerebro (mini-PC, router, UPS) | dentro de la casa | Humedad y robo ([07 §10](../referencia/07-puntos-ciegos-y-riesgos.md)) |
| Cruces de pasillos | cables y mangueras aéreos a ≥ 2 m; drenajes nunca cruzan el paso zaguán → puerta | Regla de oro de estas plantas |
| Cuarto de cosecha | bajo techo, separado del cultivo por cortina, con lavamanos y mesa inox/polietileno | NOM-251 ([research/inocuidad-operativa §4](../research/inocuidad-operativa.md)) |
| Composta | en la esquina opuesta al cultivo y a la cosecha, con tapa | Fungus gnats ([07 §12](../referencia/07-puntos-ciegos-y-riesgos.md)) |
| Sustrato usado con fusarium | fuera del área de producción el mismo día | [07 §12](../referencia/07-puntos-ciegos-y-riesgos.md) |

## 8. Cómo adaptar el plano a tu patio

1. **Levanta tu patio** en una hoja cuadriculada (1 cuadro = 0.5 m): bardas, casa, puertas, zaguán, coladera(s), toma, contacto, centro de carga, techos existentes, árboles y **pendiente del piso** (nivel de manguera: ¿hacia dónde corre el agua?). Foto de todo.
2. **Fija primero lo que no se mueve:** la coladera manda el drenaje y el rebosadero; el centro de carga manda por dónde entra el 127 V; el techo existente manda dónde va el rack de Fase 0 y el cuarto de cosecha.
3. **Coloca el túnel** con 0.6/0.8 m a bardas y la cumbrera paralela al lado largo del patio; **la puerta, del lado del zaguán**. Si el patio es más angosto que 4.2 m de ancho libre, el túnel de 3 m no cabe con pasillos: baja a 2.5 m de ancho o pon los racks en la cabecera.
4. **Pon el tinaco en la esquina más cercana a la coladera y al alero del túnel**, nunca donde tape la coladera ni donde estorbe el paso.
5. **Traza la troncal eléctrica** desde el contacto GFCI hasta la columna del túnel más cercana, siempre pegada a pared o aérea con mensajero; GAB-A donde hay techo, GAB-1 en la columna más cercana al rack testigo y al tinaco.
6. **Dibuja los drenajes** desde cada punto húmedo hasta la coladera comprobando que **ninguno cruce un pasillo**; si es inevitable, el cruce va bajo rampa pasacables y lo anotas en el plano.
7. **Edita `hardware/cad/layout.py`** (sección `GEOMETRIA`: `ACCESO`, `COLADERA`, `TOMA`, `CONTACTO`, `COBERTIZO`, `TUNEL_F1/F2`, `TINACO`, …), regenera y vuelve a leer las longitudes del bloque **Notas → Recorridos** (en el desplegable bajo cada plano, o en `docs/assets/diagramas/layout/<plano>.notas.md`): son tu lista de compra de cable, manguera y canalón.
8. **Patio en renta o condominio:** sin permiso de perforar, el anclaje son dados de ≥ 80 kg por columna y vientos ([instalacion-tunel-detalle §1](../research/instalacion-tunel-detalle.md)); verifica Art. 21/23 de la Ley de Propiedad en Condominio antes de gastar ([07 §9](../referencia/07-puntos-ciegos-y-riesgos.md)).

!!! example "Ejemplos rápidos"
    - **Patio de 8 × 10 m (largo norte–sur):** gira todo 90°: cumbrera norte–sur, puerta en la cabecera que mira al zaguán, tinaco en la esquina de la coladera. Es exactamente la orientación del render 3D.
    - **Coladera en el centro del patio:** el drenaje se acorta; cuida que el túnel no la tape (déjala en un pasillo) y que el rebosadero del tinaco llegue con ≥ 1 %.
    - **Sin cobertizo:** el rack de Fase 0 va dentro de la casa (cuarto de servicio) y el cuarto de cosecha se resuelve con un techo ligero de 2 × 2 m junto a la puerta de la casa, antes de la Fase 2.

## 9. Checklist de replanteo (antes de perforar)

- [ ] Plano propio dibujado con coladera, toma, contacto, centro de carga y pendiente del piso; foto de cada uno.
- [ ] Reserva del túnel trazada con hilo; diagonales iguales ± 1 cm; ninguna ancla a < 15 cm de borde o grieta; losa ≥ 10 cm (barreno de prueba).
- [ ] 3 días de T mín/máx y luz (Photone) medidos en el punto del rack y en la reserva.
- [ ] Coladera probada (10 L de golpe se van) y recorrido de cada drenaje marcado con gis, sin cruzar pasillos.
- [ ] Base del tinaco marcada; comprobado que el tinaco pasa por el zaguán (o por la casa) [POR VERIFICAR: Ø del Resistec 750 L en la ficha Rotoplas].
- [ ] Punto del contacto WR, trayecto del conduit y punto de la varilla de tierra acordados con el electricista (cotización por escrito).
- [ ] Trayecto de la troncal aérea marcado a 2.2 m; ningún cruce de pasillo a nivel de piso.
- [ ] Vecinos y condominio informados/consultados; uso de suelo verificado en SEDUVI ([07 §9](../referencia/07-puntos-ciegos-y-riesgos.md)).
- [ ] Longitudes del bloque **Notas → Recorridos** de la planta (desplegable bajo la imagen) copiadas a la lista de compras de Fase 1 (`docs/fases/fase-1/compras.md`).

Registrar en bitácora: una fila `SITIO-AAMMDD` en `bitacora/produccion.csv` con las medidas en `observaciones` (T mín/máx, µmol, diagonales, foto), igual que en [Montar el rack](../fases/fase-0/montaje.md). Si prefieres un `bitacora/obra.csv` aparte, créalo con `fecha,medida,valor,foto` [POR VERIFICAR: no existe aún en el repo].

## Fuentes

- [03-instalacion](../referencia/03-instalacion.md) §0.1–0.2 (sitio del rack), §1.1–1.3 (túnel, agua, seguridad eléctrica), §2 (NFT).
- [research/estructura-invernadero](../research/estructura-invernadero.md) (racks, túnel 3×6 → 5×6, anclaje y viento).
- [research/instalacion-tunel-detalle](../research/instalacion-tunel-detalle.md) §1 (anclaje), §2 (croquis y trazo), §4 (canalón, tlaloque, tinaco).
- [07-puntos-ciegos-y-riesgos](../referencia/07-puntos-ciegos-y-riesgos.md) §3 (frío), §9 (condominio), §10 (seguridad), §12 (residuos).
- [electrico.md](electrico.md), [hidraulico.md](hidraulico.md), [estructura-tunel.md](estructura-tunel.md), [rack-y-charolas.md](rack-y-charolas.md); BOM por fase en [referencia/bom.md](../referencia/bom.md) (`bom/fase1.csv`, `bom/fase2.csv`).

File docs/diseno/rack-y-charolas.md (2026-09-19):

# Rack y charolas

**En una línea:** el rack Husky de 5 niveles (183 × 91 × 46 cm) es la unidad de producción de
microgreens: 3 charolas 1020 por nivel, oscuridad arriba, luz T8 y nebulizadores en los cuatro
niveles de abajo, y cada charola **baja un nivel por etapa** hasta cosecharse a la altura de la
mano. Esta página explica el alzado, cuántas charolas caben de verdad, qué carga aguanta, cómo se
ilumina y se riega cada nivel, y por dónde circulan las charolas.

!!! info "Antes de empezar"
    - **Tiempo:** 15 min de lectura; el armado real es 1.5–2 h en
      [Fase 0 · Montar el rack](../fases/fase-0/montaje.md). · **Costo:** rack $2,019
      (verificado, Home Depot) + 20 charolas ≈ $1,200 aprox. ([BOM Fase 0](../fases/fase-0/compras.md));
      en Fase 1 se suman 8 tubos T8 ($968 verificado) + nebulizadores ($250 aprox.)
      ([BOM Fase 1](../fases/fase-1/compras.md)). · **Personas:** 1 (2 para mover el rack armado).
    - **Necesitas:** el rack, 10 charolas perforadas + 10 lisas, plástico para forrar los
      entrepaños, nivel de burbuja, calzas, 4 bloques macizos de 15 cm, masking y marcador
      ([04-herramientas](../referencia/04-herramientas.md)).
    - **Prerequisitos:** [Layout del patio](layout-patio.md) (dónde va el rack: bajo techo, sin
      sol de mediodía ni goteo, toma a < 10 m) y el SOP de siembra
      ([Sembrar una charola](../guias/sembrar-una-charola.md)).

## Vista general

Alzado del rack Husky 183 × 91 × 46 cm a escala 1:10: vista frontal con 5 niveles y 3 charolas 1020 por nivel, N5 zona blackout con pilas tapadas y peso, N1–N4 en luz con 2 tubos T8 y línea de nebulizadores por nivel, sensores MT-1…4, charola colectora a coladera; vista lateral con riser de riego; 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

??? note "Leyenda, flujo de charolas y tablas del alzado"

    --8<-- "assets/diagramas/layout/rack-alzado.notas.md"

**Cómo leerlo.** Verde = charolas y dosel (achurado más alto = más días de cultivo); ámbar =
tubos T8 y sensores; azul = línea de nebulizadores, boquillas y charola colectora; gris oscuro
translúcido = zona de oscuridad (N5); gris = entrepaños de MDF forrados. La columna de
etiquetas a la derecha del rack marca el flujo de charolas: ① siembra arriba → ⑤ cosecha
abajo; cada etapa se explica completa en el desplegable de arriba, junto con la leyenda y las
tablas de capacidad, cargas, iluminación y riego. Cotas en cm; el dibujo se genera con
`hardware/cad/layout.py` (constantes `RACK_*`, `SHELF_TOPS`, `CANOPY`).

| Modelo | Qué decide | Render | Archivo |
|---|---|---|---|
| Alzado 2D | Niveles, zonas, luz, riego, capacidad y cargas | [`rack-alzado.svg`](../assets/diagramas/layout/rack-alzado.svg) | [`hardware/cad/layout.py`](https://github.com/AndresIslas99/HomeGreen/blob/main/hardware/cad/layout.py) |
| Rack 3D | Volumen real de charolas, tubos y riser; `charolas_por_nivel`, `niveles_iluminados`, `estado_niveles` | [`rack-charolas.png`](../assets/diagramas/cad/rack-charolas.png) | [`hardware/cad/rack_charolas.scad`](https://github.com/AndresIslas99/HomeGreen/blob/main/hardware/cad/rack_charolas.scad) |

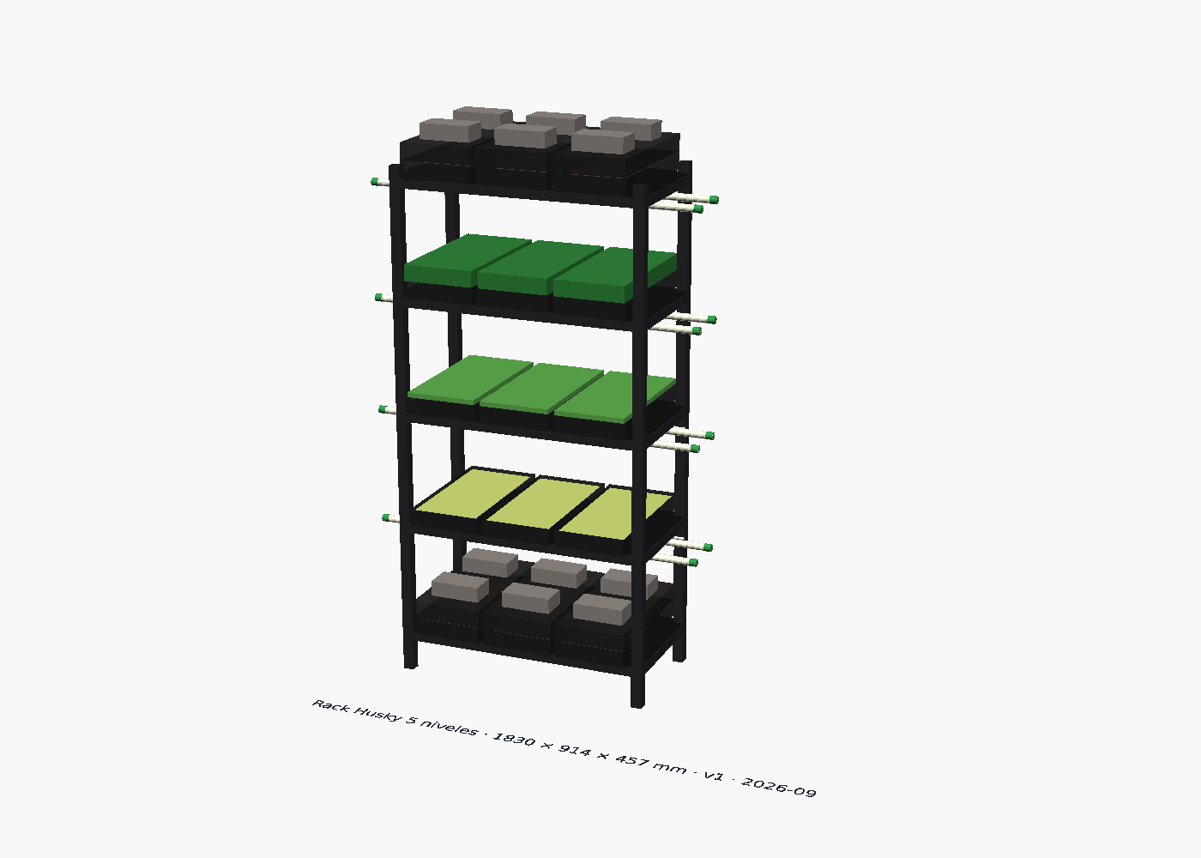
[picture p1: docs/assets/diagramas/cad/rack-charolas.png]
Render 3D del rack Husky con 3 charolas 1020 por nivel en los estados del SOP, 2 tubos T8 por nivel iluminado y riser de riego


!!! note "El render 3D muestra N1 tapado; el alzado muestra N1 en cosecha"
    Son las dos variantes de [03-instalacion §0.2](../referencia/03-instalacion.md): "nivel
    superior = germinación/oscuridad, niveles medios = desarrollo, nivel inferior = charolas recién
    sembradas (más fresco)". El alzado dibuja el **flujo normal** (N5 oscuridad → N1 cosecha); el
    render dibuja la **variante de verano** (con más de 27 °C arriba, las recién sembradas van
    abajo). Ver [§4](#4-zonas-por-nivel-y-flujo-de-charolas).

## 1. El rack: por qué el Husky y qué cambiarle

La carga nunca es el problema: una charola 1020 con coco saturado pesa 2.5–4 kg y un nivel lleno
no pasa de 40 kg. Lo que importa en un patio húmedo es **rigidez, tolerancia a la humedad y
entrepaños ajustables** ([research/estructura-invernadero §d](../research/estructura-invernadero.md)).

| Opción | Medidas (alto × ancho × fondo) | Carga por repisa | Precio | Charolas 1020 por nivel | Lectura |
|---|---|---|---|---|---|
| **Husky 5 niveles** ([Home Depot](https://www.homedepot.com.mx/p/husky-estante-de-5-niveles-de-acero-183-x-914-x-457-cm-negro-zrop361872-5llb-150281)) | 183 × 91.4 × 45.7 cm | 362.9 kg | **$2,019** verificado | **3** | La compra de Fase 0 y Fase 1; entrepaños de MDF: **forrarlos** |
| Husky ancho ([Home Depot](https://www.homedepot.com.mx/p/husky-estante-de-5-niveles-de-acero-183-x-12192-x-61-cm-negro-zrop482472-5llb-150283)) | 183 × 121.9 × 61 cm | 360 kg | $2,625 verificado | 4 (la charola de 50.8 cabe completa en 61 de fondo) | Mejor $/charola si el pasillo del túnel lo permite (30 cm más de ancho por rack) |
| HDX todo metal ([Home Depot](https://www.homedepot.com.mx/p/hdx-estante-metal-5-niveles-795-kg-de-carga-899-x-347-x-182-cm-resistente-121-755-121755)) | 182 × 89.9 × 34.7 cm | 159 kg | $2,089 verificado | 3, pero la charola vuela 16 cm | Sin MDF; el volado grande obliga a fijar las charolas: no lo recomendamos para nebulizar |
| Rack Adir galvanizado ([ML](https://www.mercadolibre.com.mx/estante-anaquel-rack-repisas-5-niveles-metalico-180x40x90-cm/p/MLM28717444)) | 180 × 90 × 40 cm | ≈ 35 kg aprox. | ≈ $1,100–1,600 aprox. | 3 (vuela 11 cm) | Versión austera de Fase 0; menos rígido, se oxida en 1–2 temporadas de riego |
| Whalen 5 repisas ([Costco](https://www.costco.com.mx/Hogar-y-Bano/Almacenaje-y-Organizacion/Estanteria-Multiusos/Whalen-Estante-de-5-Repisas-Ajustables/p/625073)) | 182.8 × 121.9 × 45.7 cm | 454 kg | agotado al 12-sep-2026 | 4 | El clásico de cuartos de cultivo; revisar en tienda física |

**Modificaciones obligatorias al Husky** ([03-instalacion §0.2](../referencia/03-instalacion.md)
y decisiones de diseño de esta wiki):

1. **Forrar cada entrepaño de MDF** con plástico grueso o poner una charola lisa debajo: el MDF
   se hincha con el primer riego que se derrama. Sube y baja los entrepaños con el rack vacío
   (se destraban a golpe de mazo de goma).
2. **Paso entre entrepaños ≥ 30 cm** (charola + brote + mano). Con 5 entrepaños en 183 cm el
   paso queda en **≈ 43 cm** (caras superiores a 10, 53, 96, 139 y 182 cm del piso en el
   alzado) [POR VERIFICAR con las posiciones reales de los postes del Husky: si los agujeros no
   coinciden, mantén ≥ 30 cm en N1–N4 y regala el sobrante a N5].
3. **Nivelar** con nivel de burbuja en los dos sentidos de cada entrepaño y **calzar las patas**:
   diferencia ≤ 1 cm entre esquinas. Una charola desnivelada encharca una esquina, y esa esquina
   es donde nace el moho.
4. **Bloques macizos de 15 cm bajo las cuatro patas** (Fase 1, decisión de
   [Layout del patio §3](layout-patio.md)): dan pendiente a la manguera de drenaje de la charola
   colectora hasta la coladera. Bloques de concreto, no ladrillo hueco.
5. **Separación ≥ 30 cm entre racks en fila**: los tubos T8 de 120 cm vuelan 14.3 cm por lado
   del rack de 91.4 cm.
6. **Tierra al chasis** del rack cuando lleve T8 (14 AWG verde desde GAB-A, [Eléctrico §6](electrico.md))
   y **una trampa amarilla pegajosa por rack** ([BOM Fase 1](../fases/fase-1/compras.md)).

## 2. Charolas 1020: doble charola y capacidad real

La charola "10×20" (1020) mide **25.4 × 50.8 cm** nominales; las mexicanas que se venden como
1020 miden 52 × 23 cm (Al Natural, $70 verificado) y las Bootstrap Farmer importadas 53.3 × 27.3
× 3.1 cm ([research/semillas-sustrato-charolas §c](../research/semillas-sustrato-charolas.md)).
El flujo estándar es **doble charola**: una perforada (drenaje) dentro de una lisa (riego por
fondo y tapa de oscuridad); para 20 charolas de Fase 0 son 10 + 10.

**Capacidad por geometría** (entrepaño de 91.4 × 45.7 cm):

| Dónde | Cuántas | Por qué |
|---|---|---|
| Por nivel, Husky 91.4 cm | **3** atravesadas | 3 × 25.4 = 76.2 cm de 91.4 (quedan 3.8 cm entre charolas); la charola de 50.8 vuela 5.1 cm sobre el fondo de 45.7 (2.5 por lado o todo al frente) |
| Por nivel, Husky 121.9 cm | 4 | 4 × 25.4 = 101.6 cm de 121.9; el fondo de 61 cm la recibe completa |
| En luz por rack (N1–N4) | **12 posiciones** | 4 niveles × 3 |
| En oscuridad por rack (N5) | 6–9 | 3 pilas de 2–3 charolas tapadas con peso |
| **En proceso por rack** | **18–21** | Suma de las dos filas anteriores |
| 3 racks (Fase 1) | 36 en luz + 18–27 en oscuridad | Ciclo de 8–12 días con ~7 días en luz: el techo es ≈ 36 charolas/semana; la meta de 25–35 pide 70–85 % de ocupación |

!!! warning "La investigación dice 8–10 por nivel: no cabe"
    [research/estructura-invernadero §d](../research/estructura-invernadero.md) afirma que en un
    nivel de 90 × 45 cm "caben 8–10 charolas 10×20". Geométricamente 8 charolas de 25 × 50 cm
    piden ~1 m² por nivel: en 0.42 m² caben 3. Toda la economía de esta wiki (30 charolas/semana
    con 3 racks, [07 §4](../referencia/07-puntos-ciegos-y-riesgos.md)) está calculada con **3 por
    nivel**. [POR VERIFICAR con el rack armado: mide el claro real entre postes; si las charolas
    compradas miden 23 cm de ancho, sigue siendo 3 (3 × 23 = 69 cm)].

En **Fase 0 el límite no es el rack sino las 10 charolas dobles del BOM** (≈ 10 en proceso,
≈ 6 cosechadas por semana); si en la semana 3 ya hay pedidos, compra 10 perforadas y 10 lisas
más ([Fase 0 · Compras](../fases/fase-0/compras.md)).

## 3. Cargas

| Elemento | Carga | Fuente / cálculo |
|---|---|---|
| Charola doble con coco saturado | 2.5–4 kg | [research/estructura-invernadero §d](../research/estructura-invernadero.md) |
| Nivel en luz (3 charolas) | 3 × 4 = **12 kg** | cálculo |
| N5 tapado (3 pilas de 2 charolas + peso de 2–4 kg) | 3 × (2 × 4 + 4) = **36 kg** | cálculo; el peso son ladrillos o una charola con agua |
| Carga viva total por rack | 4 × 12 + 36 ≈ **84 kg** | cálculo |
| Peso propio del rack | [POR VERIFICAR: dato de la caja; el Husky es acero + 5 tableros de MDF] | — |
| Capacidad de placa | 362.9 kg **por repisa**, 1,814 kg total | Home Depot (verificado) |
| Margen | > 10× por repisa | cálculo |

Reglas prácticas:

- El **centro de gravedad queda alto** (N5 es el nivel más cargado). Dentro del túnel, con
  faldones abiertos y rachas de 50–80 km/h, ancla el rack a la columna o larguero más cercano
  con una abrazadera o cincho de acero (recomendación de diseño; no está en la fuente de verdad).
- Los **4 bloques de 15 cm** deben ser macizos y estar nivelados entre sí; el rack cargado pesa
  ≈ 120–150 kg y cada pata concentra 30–40 kg en 10 cm²: en losa de concreto no hay problema,
  en piso de tierra pon una solera o placa.
- La **charola colectora** (una charola lisa o una tina baja bajo N1) recibe el goteo de todo
  el rack y drena por manguera a la coladera: es la única pieza que puede juntar más de 10 L,
  no la dejes llenarse.

## 4. Zonas por nivel y flujo de charolas

Las zonas salen del SOP de [03-instalacion §0.2–0.3](../referencia/03-instalacion.md) y de los
días por especie de [08-recetas](../referencia/08-recetas-y-economia-unitaria.md). Arriba hace
más calor (germina), abajo está más fresco (conserva): **cada charola baja un nivel por etapa**.

| Nivel | Zona | Días (típico) | Luz | Riego | Qué observas |
|---|---|---|---|---|---|
| **N5** (arriba, más cálido) | Oscuridad: pilas de 2–3 charolas tapadas con charola invertida + peso 2–4 kg, cubierta opaca | 0 → 2–4 (rábano/brócoli 2–3; girasol/chícharo 3–4; betabel 6–8) | Ninguna: sin T8 | Atomizar 1–2×/día a mano | Tallos amarillos levantan la tapa; raíces blancas parejas |
| **N4** | Destape / brote | 2–4 → 4–5 | Indirecta + T8 12–14 h | **Solo por abajo** desde aquí (agua entre la lisa y la perforada) | Verdea en 24–48 h |
| **N3** | Desarrollo | 4–8 | T8 12–14 h | Por abajo | Tallo y cotiledón abiertos |
| **N2** | Acabado | 8–10 | T8 12–14 h | Por abajo | Color y densidad finales |
| **N1** (abajo, más fresco) | Pre-cosecha → cosecha | 8–12 (betabel 13–18; cilantro 18–24) | T8 12–14 h | Suspender 12–24 h antes de cortar | Se corta la mañana de la entrega, tijera sobre el sustrato |

```mermaid
flowchart TB
    S[Siembra día 0<br/>sanitizar · remojar · densidad de 08-recetas] --> N5[N5 · Oscuridad<br/>tapada con peso 2–4 kg · 2–4 días · atomizar 1–2×/día]
    N5 --> N4[N4 · Destape<br/>luz indirecta + T8 · riego SOLO por abajo]
    N4 --> N3[N3 · Desarrollo<br/>día 4–8]
    N3 --> N2[N2 · Acabado<br/>día 8–10]
    N2 --> N1[N1 · Cosecha<br/>día 8–12 · cortar la mañana de la entrega]
    N1 --> L[Lavar y desinfectar la charola<br/>sustrato usado fuera el mismo día]
    L --> S
    style N5 fill:#e5e7eb,stroke:#1f2937
    style N4 fill:#e8f5e9,stroke:#2e7d32
    style N3 fill:#e8f5e9,stroke:#2e7d32
    style N2 fill:#e8f5e9,stroke:#2e7d32
    style N1 fill:#c8e6c9,stroke:#2e7d32
```

- **Posición en la bitácora:** el código de lote termina en la posición (`…-R1N5` = rack 1,
  nivel 5) como en [Sembrar una charola](../guias/sembrar-una-charola.md); cuando la charola
  baja de nivel no cambies el código, solo el campo `observaciones` si algo raro pasa.
- **Variante de verano** (> 27 °C en N5, junio–septiembre con HR de 70–89 %): invierte el
  arranque —las recién sembradas tapadas van a **N1**, el nivel más fresco— y la cosecha sube a
  N2; siembra ~10 % menos denso ([03 §0.3](../referencia/03-instalacion.md)).
- **Invierno** (diciembre–febrero, noches de 5–9 °C): la germinación se alarga 30–50 %; el
  tapete térmico de 380 aprox. va bajo la pila de N5 (relé K4 en Fase 1) o la pila se muda al
  punto más cálido de la casa ([Germinar en invierno](../guias/germinar-en-invierno.md)).
- **Siembras escalonadas:** con 3 posiciones por nivel y un ciclo de ~10 días, sembrar
  lunes y jueves llena N5 cada vez con 3–6 charolas y mantiene una charola cosechable en N1
  casi todos los días de entrega ([Fase 1 · índice](../fases/fase-1/index.md)).

## 5. Iluminación

| Parámetro | Valor | Fuente |
|---|---|---|
| Tubo | LED T8 18 W, 120 cm, 6500 K, 1,400 lm — **$121 c/u verificado** ([JWJ Light](https://jwjlight.mx/producto/tubo-led-t8-18w-120-cm/)) | [research/clima-agronomia §8](../research/clima-agronomia.md) |
| Por nivel | 2 tubos bajo el entrepaño de arriba, a 3 cm de su cara inferior, sobre el eje de la 1.ª y 3.ª charola | alzado |
| Por rack | 8 tubos (N1–N4; N5 no lleva) = 144 W; **$968** + canaletas y cable ≈ $400 aprox. | [BOM Fase 1](../fases/fase-1/compras.md) |
| Horario | 12–14 h/día por el relé K3 → contactor K5 en GAB-A (fusible F5 2 A, 14 AWG en canaleta, tierra al chasis) | [Eléctrico §1 y §6](electrico.md) |
| Consumo | 8 × 18 W × 13 h ≈ 1.9 kWh/día ≈ 52–60 kWh/mes ≈ $60–90/mes por rack | [02-restricciones](../referencia/02-restricciones-y-requisitos.md), [Eléctrico](electrico.md) |
| Meta de luz en la charola | 100–200 µmol/m²s (app Photone, a la altura de la charola) | [03 §0.1](../referencia/03-instalacion.md) |
| Distancia luz → dosel | 20–27 cm con paso de 43 cm (2 cm de brote en N4 hasta 9 cm de cosecha en N1) | alzado |
| Espectro | 6500 K estándar basta para un ciclo de 10 días sin floración: **no compres "grow lights"** | [research/clima-agronomia §8](../research/clima-agronomia.md) |

!!! danger "24 tubos y la tarifa DAC"
    El BOM de Fase 1 presupuesta **8 tubos: un rack**. Iluminar los 3 racks son 24 tubos
    (≈ $2,900), 432 W y ≈ 5.6 kWh/día ≈ 170 kWh/mes: con el consumo del hogar eso cruza los
    250 kWh/mes que reclasifican a **DAC** ([07 §1](../referencia/07-puntos-ciegos-y-riesgos.md)).
    Regla: mide primero con Photone; en CDMX la luz natural indirecta de un túnel con plástico
    al 25 % suele cubrir N2–N4, y noviembre–febrero es la época más soleada. Ilumina solo los
    niveles que no lleguen a 100 µmol/m²s y auditá el recibo con el medidor de enchufe antes de
    comprar el segundo juego [POR VERIFICAR: lectura Photone por nivel en tu túnel].

Ajuste fino: si un nivel en luz no llega a 100 µmol/m²s con los T8 encendidos, baja una posición
el entrepaño de arriba (acerca el tubo al dosel) antes de comprar más tubos; si pasa de
200 µmol/m²s en brote (N4), sube el entrepaño o apaga un tubo [POR VERIFICAR con luxómetro o
Photone: la equivalencia lm → µmol depende del espectro del tubo].

## 6. Riego por nivel

| Elemento | Cómo va en el rack | Fuente |
|---|---|---|
| Línea de nebulizadores | Una por nivel N1–N4, atrás, 2 cm bajo los tubos, con **2 boquillas** sobre las charolas 1 y 3; N5 se atomiza a mano | [Hidráulico §1](hidraulico.md) |
| Riser | Tubo ½" por el poste trasero desde el manifold de P-1 (diafragma 12 V con presostato, 4–6 L/min); **una válvula manual por nivel** para igualar caudal y para apagar un nivel completo cuando ese lote ya destapó | [Hidráulico §1](hidraulico.md) |
| Sensores | MT-1…MT-4 capacitivos, uno en la **charola testigo** (la primera) de cada nivel en luz del rack 3; conector hacia arriba y encintado; SHT31 de T/HR en el poste a ~1.1 m | [Eléctrico §1](electrico.md), [Fase 1 · Automatización](../fases/fase-1/automatizacion-v1.md) |
| Lógica | Histéresis por nivel (máx. N ciclos/h) con interlock de nivel de tinaco LT-1 < 20 % | [06-validacion L0](../referencia/06-validacion-y-lazos-agenticos.md) |
| Riego tras el destape | **Solo por abajo**: agua entre la charola lisa y la perforada; mojar el follaje desde N4 hacia abajo es invitar al moho | [03 §0.3](../referencia/03-instalacion.md) |
| Drenaje | Charola colectora bajo N1 → manguera → coladera (≈ 12 m con ≥ 1 % en el supuesto; por eso los bloques de 15 cm) | [Layout del patio §3](layout-patio.md) |
| Fase 0 | Sin bomba: atomizador de 1 L para la oscuridad y regadera/jarra para el riego por fondo | [BOM Fase 0](../fases/fase-0/compras.md) |

!!! warning "Nebulizadores sí, pero no sobre el follaje"
    Los nebulizadores sirven para la oscuridad (N5 a mano o N1 en verano), para hidratar el
    sustrato antes de sembrar y para la temporada seca (marzo–mayo). Una charola destapada se
    riega por abajo; si el nivel entero ya destapó, cierra su válvula ([Hidráulico §1](hidraulico.md)).

## Al terminar

- [ ] Rack forrado, nivelado (≤ 1 cm entre esquinas) y con paso ≥ 30 cm en N1–N4; niveles rotulados N1–N5 con masking.
- [ ] 3 charolas dobles caben en cada nivel sin forzar y el volado queda al frente.
- [ ] Charola colectora bajo N1 drenando a la coladera (Fase 1: sobre bloques de 15 cm).
- [ ] Lectura Photone por nivel anotada (antes y después de instalar T8).
- [ ] Fase 1: T8 encienden desde HA por K5, fusible F5 y tierra al chasis medidos; boquillas rocían parejo en los 4 niveles y cada válvula cierra sola su nivel.
- Registrar en bitácora: `bitacora/produccion.csv`, fila `SITIO-AAMMDD` con las lecturas de luz por nivel en `observaciones`; cada charola sembrada lleva su posición `RxNy` en `siembra_id`.
- Siguiente paso: [Sembrar una charola](../guias/sembrar-una-charola.md) y, en Fase 1, [Automatización v1](../fases/fase-1/automatizacion-v1.md).

## Fuentes

- [03-instalacion](../referencia/03-instalacion.md) §0.1 (sitio y luz), §0.2 (rack, zonas por nivel, separación ≥ 30 cm), §0.3 (SOP: oscuridad, destape, riego por abajo, cosecha).
- [research/estructura-invernadero §d](../research/estructura-invernadero.md) (racks, capacidad de carga, peso de charola, precios verificados).
- [research/semillas-sustrato-charolas §c](../research/semillas-sustrato-charolas.md) (charolas 1020, doble charola, precios).
- [research/clima-agronomia §8](../research/clima-agronomia.md) y [02-restricciones](../referencia/02-restricciones-y-requisitos.md) (T8 6500 K, fotoperiodo, consumo).
- [08-recetas](../referencia/08-recetas-y-economia-unitaria.md) (días por especie, densidades), [07 §1 y §4](../referencia/07-puntos-ciegos-y-riesgos.md) (DAC, 30 charolas/semana).
- [Eléctrico](electrico.md) (K5, fusibles, calibres), [Hidráulico](hidraulico.md) (P-1, manifold, nebulizadores), [Layout del patio](layout-patio.md) (posición, drenaje, separación entre racks); `bom/fase0.csv`, `bom/fase1.csv`.

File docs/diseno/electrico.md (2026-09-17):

# Diseño eléctrico

**En una línea:** cómo se alimenta, se protege y se cablea todo lo eléctrico del huerto (dos nodos ESP32, relés, bombas, luces y el respaldo del NFT) para que nadie se electrocute con las manos mojadas, nada se incendie y la bomba del NFT no se detenga cuando CFE corte la luz.

!!! info "Antes de empezar"
    - **Tiempo:** 30 min de lectura; el armado se reparte en [Fase 1](../fases/fase-1/automatizacion-v1.md) (nodo de riego) y [Fase 2](../fases/fase-2/electrico-respaldo.md) (NFT + respaldo). · **Costo:** electrónica v1 ~$3,200–4,800; paquete respaldo + seguridad ~$8,500–14,500 (fuente: [research/electrico-respaldo-seguridad.md §6](../research/electrico-respaldo-seguridad.md)). · **Personas:** tú + medio día de electricista certificado para GFCI y tierra.
    - **Necesitas:** las listas de [compras Fase 1](../fases/fase-1/compras.md) y [compras Fase 2](../fases/fase-2/compras.md) (o el [BOM por fase](../referencia/bom.md)), multímetro, cautín, prensaestopas y dos gabinetes IP65.
    - **Prerequisitos:** [Antes de gastar un peso](../empieza-aqui/antes-de-gastar-un-peso.md) (consumo actual del recibo CFE y tarifa DAC), [Instalar GFCI y tierra](../guias/instalar-gfci-y-tierra.md), [Montar gabinete IP65](../guias/montar-gabinete-ip65.md).

## Visión general

Seis reglas que gobiernan todo el diseño; cada esquema de abajo es una de ellas hecha dibujo:

1. **Seguridad antes del primer relé.** El patio es "lugar mojado" según la NOM-001-SEDE-2012: GFCI en todo el circuito exterior, contacto WR con tapa "in-use", tierra física real (≤ 25 Ω) y toda la electrónica en gabinete IP65 ([03-instalacion §1.3](../referencia/03-instalacion.md)).
2. **127 V CA y 12 V CC nunca en el mismo gabinete.** Gabinete A (CA: cargador, fuente 12 V) y gabinete B (CC: fusiblera, relés, buck, ESP32).
3. **DC-first para el NFT.** La bomba de recirculación es de 12 V y cuelga de una batería LiFePO4 que está *siempre* en paralelo con el cargador: el corte de CFE no se conmuta, no se nota ([03-instalacion §2.3](../referencia/03-instalacion.md)).
4. **El fail-safe es físico, no de software.** La bomba principal va por un contacto normalmente cerrado (NC): sin ESP32, sin Wi-Fi y sin Home Assistant, la bomba sigue.
5. **Cada fusible protege un cable, no una carga.** Fusible principal en el borne de la batería y una fusiblera con un fusible por rama.
6. **Tierra común en estrella.** Todos los retornos de 12 V a una sola barra; la tierra física de 127 V va al chasis de los gabinetes, no a esa barra.

```mermaid
flowchart LR
    CFE[CFE 127 V CA] --> GFCI[Breaker GFCI QO120GFI 20 A<br/>centro de carga]
    GFCI --> WR[Contacto WR + tapa in-use<br/>patio]
    WR --> GA[Gabinete A · IP65 · 127 V CA]
    GA --> F12[Fuente 12 V 5 A<br/>Fase 1]
    GA --> CARG[Cargador LiFePO4 14.6 V<br/>Fase 2]
    F12 --> N1[Nodo de riego v1<br/>rack de microgreens]
    CARG --> BUS[Bus 12.8 V<br/>batería LiFePO4 100 Ah en paralelo]
    PV[Panel 100 W + EPEVER<br/>opcional] -.-> BUS
    BUS --> FUS[Fusiblera 6 vías]
    FUS --> B1[Bomba NFT principal · K1 NC]
    FUS --> B2[Bomba NFT respaldo · K2 NO]
    FUS --> N2[Nodo NFT v2<br/>pH/EC · dosificación · detector de red]
    TIERRA[Varilla copperweld 5/8 x 3 m<br/>≤ 25 Ω] --- GFCI
    style GFCI fill:#fff7ed,stroke:#b45309
    style WR fill:#fff7ed,stroke:#b45309
    style GA fill:#fff7ed,stroke:#b45309
    style BUS fill:#f0fdf4,stroke:#2e7d32
    style FUS fill:#f0fdf4,stroke:#2e7d32
```

| Esquema | Qué resuelve | Fase | Script que lo genera |
|---|---|---|---|
| [Nodo de riego v1](#1-nodo-de-riego-v1) | Riego por histéresis, ventilación, luces T8, nivel de tinaco | 1 | `hardware/electrico/nodo_riego_v1.py` |
| [Nodo NFT v2](#2-nodo-nft-v2) | pH/EC, dosificación, flujo, detector de red CFE, voltaje de batería | 2 | `hardware/electrico/nodo_nft_v2.py` |
| [Bus DC-first](#3-bus-dc-first) | Continuidad de la bomba NFT ante cortes (batería + fusiblera + K1/K2) | 2 | `hardware/electrico/bus_dc_first.py` |
| [Tablero, GFCI y tierra](#4-tablero-gfci-y-tierra-fisica) | Circuito de 127 V del patio, GFCI, contacto intemperie, electrodo de tierra | 1 | `hardware/electrico/tablero_gfci_tierra.py` |
| [Alimentación del ESP32](#5-alimentacion-y-proteccion-del-esp32) | 12 V → 5 V → 3V3, desacoplo, tierra en estrella, presupuesto de corriente | 1 y 2 | `hardware/electrico/alimentacion_esp32.py` |

Los cinco SVG viven en `docs/assets/diagramas/electrico/` y se regeneran con `python3 hardware/electrico/<script>.py` (necesitan `schemdraw` 0.23). Cada uno lleva título, leyenda, fuentes y la marca `v1 · 2026-09`.

## Los cinco esquemas

### 1. Nodo de riego v1

Esquema del nodo de riego v1: ESP32 con 4 sensores capacitivos, SHT31, DS18B20, JSN-SR04T y módulo relé de 4 canales

**Qué muestra.** El nodo que vive en el gabinete IP65 junto al rack: un ESP32 DevKit V1 lee 4 sensores capacitivos de humedad de sustrato (uno por nivel del rack), el SHT31 de temperatura/humedad ambiente, el DS18B20 del tinaco y el JSN-SR04T de nivel; y manda un módulo relé de 4 canales que conmuta la bomba de diafragma de 12 V (riego por nebulizadores), el ventilador, las luces T8 y una reserva.

**Decisiones clave.**

- Los 4 capacitivos van a **ADC1** (GPIO32–35): ADC2 deja de funcionar en cuanto el Wi-Fi está activo. GPIO34/35 son solo entrada, perfectos para sensores.
- El ECHO del JSN-SR04T es de 5 V: divisor 10 kΩ / 20 kΩ antes de GPIO18. El TRIG va directo (el módulo acepta 3.3 V).
- Las luces T8 (8 × 18 W = 144 W, [bom/fase1.csv](../referencia/bom.md)) **no** se conmutan con el contacto del módulo relé de 5 V: el canal K3 excita la bobina de 12 V de un relé de potencia/contactor que vive en el gabinete de CA. Así el módulo relé nunca ve 127 V.
- K4 queda libre para el tapete térmico de dic–feb (mismo esquema que K3) o la luz del quinto nivel.
- Alimentación: fuente Steren ELI-1260 12 V 5 A ($399, [research/electronica-automatizacion.md §2](../research/electronica-automatizacion.md)) con fusible general F0 5 A, y un buck LM2596 ajustado a 5.0 V para el ESP32, el módulo relé y el JSN-SR04T. Para intemperie, la alternativa Mean Well IP67 XLG-75-12-A.

**Cómo leerlo.** Verde = alimentación CC; ámbar = 127 V (solo dentro del gabinete de CA); negro = señal 3.3 V. Las entradas del módulo relé son activas en bajo: en ESPHome el `switch` lleva `inverted: true`.

### 2. Nodo NFT v2

Esquema del nodo NFT v2: ESP32 con placa pH, TDS, DS18B20, YF-S201, detector de red CFE, divisor de batería, driver MOSFET de 5 canales y relé de 2 canales

**Qué muestra.** El nodo de Fase 2, alimentado desde el bus de batería (por eso sigue midiendo y avisando durante un corte). Entradas: placa pH (PH-4502C para validar el lazo, DFRobot Gravity cuando el NFT venda), TDS SEN0244, DS18B20 del depósito, YF-S201 de flujo, detector de presencia de red CFE y divisor 47 kΩ / 10 kΩ para leer el voltaje de la batería. Salidas: 3 peristálticas (A, B, pH−) y 2 solenoides ½" NC vía driver MOSFET, y un módulo relé de 2 canales para las bombas principal (K1) y respaldo (K2) del bus.

**Decisiones clave.**

- **Sondas pH y TDS en el retorno** del NFT, nunca junto a la salida de dosificación ([03-instalacion §2.2](../referencia/03-instalacion.md)). Filtro RC 1 kΩ / 100 nF en cada entrada ADC: el ADC del ESP32 es ruidoso y las sondas son de alta impedancia.
- **Detector de red CFE aislado.** Un cargador USB de 5 V enchufado al contacto GFCI del patio alimenta el LED de un optoacoplador PC817 (470 Ω en serie); el fototransistor lleva GPIO23 a 3V3 cuando hay 127 V. GPIO23 se configura `INPUT_PULLDOWN` (más 10 kΩ externo). El GND del cargador USB **no** se une al GND del nodo: esa es la gracia del optoacoplador.
- **Divisor de batería 47k/10k → GPIO36:** 14.6 V (absorción del cargador) se vuelven 2.56 V; en ESPHome `attenuation: 12db` y `multiply: 5.7` ([research/electrico-respaldo-seguridad.md §5.1](../research/electrico-respaldo-seguridad.md)).
- **GPIO12 es pin de arranque (strapping):** si está alto al encender, el ESP32 no arranca. Lleva pull-down de 10 kΩ obligatorio y se maneja por MOSFET (no por módulo relé activo en bajo, que lo dejaría alto).
- **K1 por contacto NC:** con el ESP32 apagado o GPIO32 en bajo, la bomba principal está encendida. Solo se energiza K1 para apagarla (mantenimiento). K2 (NO, en GPIO14) enciende la bomba de respaldo cuando el YF-S201 reporta flujo cero con bomba comandada. **La principal va en GPIO32 y no en GPIO14 a propósito:** GPIO14 emite un pulso al arrancar el ESP32 y en la principal eso sería un corte breve del riego.
- Solenoides **NC**: un corte de luz no vacía el tinaco ([bom/fase2.csv](../referencia/bom.md)).

### 3. Bus DC-first

Esquema del bus DC-first: CFE, GFCI, cargador LiFePO4, batería 100 Ah en paralelo, fusible principal, seccionador, fusiblera y bombas con relevadores de transferencia

**Qué muestra.** La arquitectura de continuidad ([03-instalacion §2.3](../referencia/03-instalacion.md)): CFE → GFCI → contacto intemperie → cargador LiFePO4 (14.4–14.6 V absorción, ≤ 13.6 V flotación) → nodo +BUS. La batería Epcom LI100A12PRO (12.8 V 100 Ah, $4,459 verificado) se conecta a ese mismo nodo a través de un fusible principal F0 de 30 A a ≤ 30 cm del borne y un seccionador S1. De la fusiblera salen F1 (bomba principal, 10 A, contacto K1 NC), F2 (bomba respaldo, 10 A, K2 NO), F3 (nodo NFT, 2 A), F4 (peristálticas y solenoides, 5 A), F5 (reserva) y F6 (libre). El panel Ugreen de 100 W con controlador EPEVER LS2024B es opcional y se conecta en paralelo al mismo nodo.

**Por qué así y no con inversor.** Respaldar la periférica de 0.5 HP a 120 V exigiría ~680 Ah y >$30,000 en baterías; una bomba de diafragma de 12 V de 40 W necesita ~40 Ah para 12 h ([research/electrico-respaldo-seguridad.md §2](../research/electrico-respaldo-seguridad.md)). La periférica de 127 V queda solo para llenado y purga.

El comportamiento en el tiempo (corte → batería → respaldo → restauración) está animado en [dc-first-failover.svg](../assets/diagramas/animaciones/dc-first-failover.svg) y se prueba con el [simulacro de apagón](../guias/simulacro-de-apagon.md) (validación [V11](../validacion/v11-apagon.md)).

### 4. Tablero, GFCI y tierra física

Esquema del tablero: centro de carga con breaker QO120GFI, conductores L/N/T al contacto intemperie, gabinetes A y B, y electrodo de tierra copperweld con conductor calibre 8

**Qué muestra.** El circuito de 127 V que sale de la casa al patio: breaker Square D QO120GFI de 20 A ($1,159 verificado) en el centro de carga, conductores calibre 12 AWG THW-LS en conduit hasta un contacto dúplex WR con tapa "in-use" (~$249 aprox.), clavija de uso rudo SJT al gabinete A (CA) y de ahí 12 V al gabinete B (CC). Abajo, el electrodo: varilla copperweld 5/8" × 3 m unida con abrazadera de bronce o soldadura exotérmica a un conductor calibre 8 AWG continuo hasta la barra de tierra del centro de carga. El puente de unión neutro–tierra existe **solo** en el centro de carga principal.

**Qué pedirle al electricista.** Los 25 Ω medidos con telurómetro por escrito; si sale más, segunda varilla en paralelo o intensificador de tierra (GEM). Botón TEST del GFCI cada mes. Si el presupuesto no da para el breaker GFCI, la alternativa mínima es un contacto GFCI Square D ($389) aguas arriba de todo lo del patio ([research/electrico-respaldo-seguridad.md §3.6](../research/electrico-respaldo-seguridad.md)).

!!! danger "GFCI y tierra no se sustituyen entre sí"
    El GFCI dispara con ~5 mA de fuga y protege personas; la tierra da camino de falla y protege equipos. Se necesitan los dos. Un GFCI que "dispara mucho" está detectando una fuga real (una fuente goteada, un cable pelado en el tinaco): se busca la fuga, no se quita el GFCI.

### 5. Alimentación y protección del ESP32

Esquema de alimentación: 12 V, fusible, diodo Schottky, capacitores, buck LM2596 a 5 V, ESP32 con LDO interno y riel de 3V3 para sensores

**Qué muestra.** El bloque que se repite en ambos nodos: +12 V (de la fusiblera o de la fuente) → fusible 2 A → diodo Schottky 1N5822 contra polaridad invertida → C1 100 µF (+ TVS SMBJ15A opcional para los picos de la bomba) → buck LM2596 ajustado a 5.0 V **antes** de conectar el ESP32 → C2 470 µF + C3 100 nF → VIN. El regulador AMS1117 interno entrega los 3V3 para sensores; C5 10 µF + C6 100 nF en ese riel y 100 nF junto a cada sensor. C4 100 nF en EN evita arranques fallidos cuando la fuente tiene huecos.

**Regla de oro:** el 3V3 del ESP32 solo alimenta sensores (decenas de mA). Relés, bombas y ventiladores se alimentan del 12 V (por su propio fusible) o del 5 V del buck (módulo relé), nunca del ESP32.

## Tabla de pines por nodo

Los pines de esta tabla son los que usa el firmware (`firmware/esphome/nodo-riego-v1.yaml` y `nodo-nft-v2.yaml`, documentados en [Firmware ESPHome](../software/firmware.md)). Si cambias un pin, cámbialo en los tres lugares: YAML, script del esquema y esta tabla.

### Nodo de riego v1 (ESP32 DevKit V1, 30 pines)

| GPIO | Canal | Función | Periférico | Componente ESPHome | Notas |
|---|---|---|---|---|---|
| 32 | ADC1_CH4 | entrada analógica | Capacitivo S1 (nivel 1) | `adc`, `attenuation: 12db` | ADC1 funciona con Wi-Fi activo |
| 33 | ADC1_CH5 | entrada analógica | Capacitivo S2 (nivel 2) | `adc` | |
| 34 | ADC1_CH6 | entrada analógica | Capacitivo S3 (nivel 3) | `adc` | solo entrada, sin pull-up interno |
| 35 | ADC1_CH7 | entrada analógica | Capacitivo S4 (nivel 4) | `adc` | solo entrada |
| 21 | SDA | I2C | SHT31 (dirección 0x44) | `i2c`, `sht3xd` | pull-ups 4.7 kΩ a 3V3 si el módulo no los trae |
| 22 | SCL | I2C | SHT31 | `i2c` | |
| 4 | — | 1-Wire | DS18B20 tinaco | `one_wire`, `dallas_temp` | pull-up 4.7 kΩ a 3V3 |
| 5 | — | salida digital | JSN-SR04T TRIG | `ultrasonic` | pin de arranque: como salida no da problema |
| 18 | — | entrada digital | JSN-SR04T ECHO | `ultrasonic` | divisor 10 kΩ / 20 kΩ (ECHO es de 5 V) |
| 25 | — | salida | Relé K1: bomba diafragma 12 V | `switch` gpio, `inverted: true` | módulo activo en bajo |
| 26 | — | salida | Relé K2: ventilador 12 V | `switch` | |
| 27 | — | salida | Relé K3 → relé de potencia K5: luces T8 127 V | `switch` | K5 vive en el gabinete de CA |
| 14 | — | salida | Relé K4: reserva (tapete térmico / luz nivel 5) | `switch` | |
| VIN | — | 5 V | buck LM2596 | — | nunca USB y VIN a la vez |
| 3V3 | — | 3.3 V salida | capacitivos, SHT31, DS18B20 | — | ≤ 600 mA en total, solo sensores |

### Nodo NFT v2 (ESP32 DevKit V1, 30 pines)

| GPIO | Canal | Función | Periférico | Componente ESPHome | Notas |
|---|---|---|---|---|---|
| 34 | ADC1_CH6 | entrada analógica | Placa pH (Po) vía RC 1 kΩ / 100 nF | `adc` | solo entrada; Po ≤ 3.1 V ajustando el offset con buffer 4.01 |
| 35 | ADC1_CH7 | entrada analógica | TDS SEN0244 (AOUT) vía RC | `adc` | calibrar en mS/cm con patrón 1.413 |
| 36 | ADC1_CH0 (VP) | entrada analógica | Divisor 47 kΩ / 10 kΩ del bus 12.8 V | `adc`, `multiply: 5.7` | 14.6 V → 2.56 V |
| 4 | — | 1-Wire | DS18B20 del depósito | `one_wire`, `dallas_temp` | pull-up 4.7 kΩ |
| 27 | — | contador de pulsos | YF-S201 (≈ 450 pulsos/L) vía divisor 10k/20k | `pulse_counter` | señal Hall de 5 V |
| 23 | — | entrada digital | Detector de red CFE (PC817 desde cargador USB) | `binary_sensor` gpio, `INPUT_PULLDOWN` | 127 V presente → 1; GND_USB aislado |
| 25 | — | salida | Peristáltica A (12 V) vía MOSFET | `switch` | canal típico: 220 Ω gate, 10 kΩ pull-down, 1N5819 flyback |
| 26 | — | salida | Peristáltica B | `switch` | |
| 33 | — | salida | Peristáltica pH− (AquAcid) | `switch` | |
| 12 | — | salida | Solenoide llenado ½" NC | `switch` | **pin de arranque: pull-down 10 kΩ obligatorio** |
| 13 | — | salida | Solenoide purga ½" NC | `switch` | |
| 32 | — | salida | Relé K1 (contacto **NC**) → bomba NFT principal | `switch`, `RESTORE_DEFAULT_ON` | reposo = bomba ON (fail-safe) |
| 14 | — | salida | Relé K2 (contacto NO) → bomba NFT respaldo | `switch` `inverted: true`, `RESTORE_DEFAULT_OFF` | GPIO14 emite un pulso al arrancar el ESP32: en el respaldo (NO) es un parpadeo inofensivo; en la principal sería un corte |
| 16, 17 | — | entradas | Flotadores "tambo alto" / "tambo bajo" (LT-2, **opcionales**) | `binary_sensor` gpio, `INPUT_PULLUP` | cierran a GND; sin flotador, pines al aire y el interlock de nivel queda desactivado. LT-2 no está en `bom/fase2.csv` [POR VERIFICAR: elegir flotador con contacto o un segundo JSN-SR04T y agregarlo al BOM] |
| VIN | — | 5 V | buck desde F3 del bus | — | |

!!! note "Diferencias con el YAML del informe de investigación"
    El YAML de ejemplo en [research/electrico-respaldo-seguridad.md §5.1](../research/electrico-respaldo-seguridad.md) usa GPIO34 para el voltaje de batería, GPIO26 para la red CFE y GPIO25/33 para las bombas. Aquí GPIO34/35 quedan para pH/TDS (ADC1 de solo entrada), el voltaje va a GPIO36, la red CFE a GPIO23 y las bombas a GPIO32 (principal, K1 NC) y GPIO14 (respaldo, K2 NO), para que un solo nodo cubra dosificación **y** continuidad. La lógica de las 5 automatizaciones del informe no cambia; solo los pines.

    La asignación que manda es siempre la de [`firmware/esphome/nodo-nft-v2.yaml`](https://github.com/AndresIslas99/HomeGreen/blob/main/firmware/esphome/nodo-nft-v2.yaml): si esta tabla y el YAML difieren, el YAML es el que se flashea ([Firmware § Nodo NFT v2](../software/firmware.md#nodo-nft-v2)).

**Pines que no se usan en ningún nodo y por qué:** GPIO0, GPIO2 y GPIO15 (pines de arranque: pueden impedir el flasheo o el boot), GPIO6–11 (flash interna), GPIO1/3 (UART0 del USB). GPIO19 queda libre para ampliaciones (p. ej. un segundo DS18B20 o un LED de estado); GPIO16/17 quedan libres **solo si no pones los flotadores opcionales del tambo**.

## Tabla de cableado

Criterio de diseño: caída de tensión ≤ 3 % (0.36 V en 12 V, 3.8 V en 127 V) con la resistencia tabulada del cobre (8 AWG ≈ 2.1 Ω/km, 10 ≈ 3.3, 12 ≈ 5.2, 14 ≈ 8.3, 16 ≈ 13.2, 18 ≈ 21, 22 ≈ 53) y longitud de ida y vuelta. Los calibres de 127 V los confirma el electricista contra la tabla de ampacidad de la NOM-001 [POR VERIFICAR: tabla 310-15 de la NOM-001-SEDE-2012 y ficha del cable comprado].

| Tramo | Corriente de diseño | Calibre | Colores | Longitud máx. | Protección | Notas |
|---|---|---|---|---|---|---|
| Centro de carga → contacto WR del patio (127 V) | 20 A (breaker) | 12 AWG THW-LS ×3 en conduit | L negro · N blanco · T verde/desnudo | 18 m a 20 A (la carga real es < 5 A: sobra) | QO120GFI 20 A | sin empalmes fuera de caja |
| Contacto WR → gabinete A | 15 A | SJT 3 × 14 AWG uso rudo | negro/blanco/verde | 3 m | el mismo GFCI | clavija con tapa "in-use" cerrada |
| K5 (relé de potencia) → tubos T8 (127 V) | 1.2 A (144 W) | 14 AWG | negro/blanco/verde | 15 m | F5 2 A | dentro de canaleta, tierra al chasis del rack |
| Borne + de batería → fusiblera | 30 A | 10 AWG (o 8 AWG) | rojo / negro | 1.5 m | F0 30 A a ≤ 30 cm del borne | terminales de ojillo, tuerca con arandela de presión |
| Fusiblera → bomba NFT 12 V (×2) | 5 A (60 W) | 14 AWG | rojo / negro | 4 m (6 m con 12 AWG) | F1, F2 10 A | contacto K1/K2 en el positivo |
| Fusiblera → peristálticas y solenoides | ≤ 1 A por canal [POR VERIFICAR: corriente en la ficha del vendedor] | 18 AWG | rojo / negro | 8 m | F4 5 A | retorno de cada carga a la barra, no al ESP32 |
| Fuente 12 V 5 A → bomba diafragma / ventilador (nodo riego) | 5 A / 2 A | 14 AWG / 18 AWG | rojo / negro | 4 m / 8 m | F1 5 A / F2 2 A | |
| Fusiblera o fuente → buck del nodo | 0.7 A | 18 AWG | rojo / negro | 5 m | F3 2 A (F0 5 A en riego) | |
| Buck → VIN del ESP32 | 0.7 A | 18–20 AWG | rojo / negro | 0.3 m | — | más largo = brownout al transmitir Wi-Fi |
| Capacitivos de sustrato (3 hilos) | mA | 22–24 AWG blindado o par trenzado | rojo 3V3 · negro GND · amarillo AOUT | 3 m (regla práctica, señal analógica) | — | conector hacia arriba y sellado |
| SHT31 (I2C, 4 hilos) | mA | 22–24 AWG blindado | rojo · negro · azul SDA · blanco SCL | 1–2 m (regla práctica a 100 kHz) | — | pull-ups 4.7 kΩ |
| DS18B20 (1-Wire, 3 hilos) | mA | 22 AWG | rojo · negro · amarillo DQ | 10 m con 4.7 kΩ (regla práctica) | — | el sumergible ya trae 1–3 m |
| JSN-SR04T | mA | el cable del módulo (2.5 m) | — | no alargar más de 5 m [POR VERIFICAR: ficha del módulo] | — | zona muerta ~20 cm sobre el nivel máximo |
| YF-S201 | mA | 22 AWG | rojo · negro · amarillo | 5 m | — | divisor 10k/20k en el nodo |
| Electrodo pH (BNC) | — | el coaxial del electrodo | — | **no se alarga** (alta impedancia) | — | placa pH cerca del retorno |
| Tierra física: barra del tablero → varilla | falla | 8 AWG desnudo o verde | verde | la mínima posible, continuo | — | abrazadera de bronce o soldadura exotérmica |
| Tierra de equipo: contacto → chasis de gabinetes | falla | 12 AWG | verde | con el circuito | — | nunca a tubería ni al neutro |

Código de colores en CC: **rojo** +12 V, **negro** GND, **naranja** +5 V, **amarillo** señales analógicas, **azul/blanco** I2C. Etiqueta cada extremo con cinta y marcador: el mantenimiento de las 2 a. m. lo agradece.

## Consumo y autonomía de la batería

Números de la fuente ([research/electrico-respaldo-seguridad.md §2.3 y §3.5](../research/electrico-respaldo-seguridad.md)):

- Bomba de diafragma 12 V de 40 W → 3.3 A. 12 h continuas = 480 Wh ≈ 38–40 Ah.
- Fórmula: `autonomía [h] = Ah × DoD × 12.8 V ÷ P [W]`. Con LiFePO4 100 Ah al 90 % DoD y 40 W: 100 × 0.9 × 12.8 ÷ 40 = 28.8 h (la fuente redondea a 28–30 h). Sumar el nodo NFT (≈ 2 W [POR VERIFICAR: medir con multímetro en el banco de pruebas, V3]) baja a ≈ 27 h.
- Modo supervivencia 15 min ON / 15 min OFF (el NFT lo tolera; la película y la esponja retienen humedad): consumo a la mitad → ≈ 2.5 días.

| Batería | Ah útiles | Bomba 40 W continua | Modo 15/15 | Costo (fuente) |
|---|---|---|---|---|
| LiFePO4 100 Ah Epcom LI100A12PRO (90 % DoD) | 90 Ah | 28–30 h | ≈ 2.5 días | $4,459 verificado |
| LiFePO4 50 Ah (90 % DoD) | 45 Ah | 13–14 h | ≈ 27 h | aprox. $2,300–3,200 |
| AGM 100 Ah (50 % DoD sano) | 50 Ah | 15 h | ≈ 30 h | aprox. $3,000–4,500 |
| Steren BR-1224 24 Ah plomo sellada (arranque austero) | ~12 Ah | — | ≈ 7 h | $1,290 verificado |

**Solar.** CDMX tiene 5.0–5.5 h solares pico; un panel de 100 W produce ≈ 450–500 Wh/día y la bomba 24/7 consume ≈ 960 Wh/día: el panel **no** sostiene la operación (harían falta 250–300 W), pero flota la batería sin CFE y en un corte diurno la estira a varios días. Por eso es "Fase 2.5", no día 1.

**Energía mensual estimada de todo el huerto** (para vigilar el umbral DAC de 250 kWh/mes de promedio móvil, [07-puntos-ciegos §1](../referencia/07-puntos-ciegos-y-riesgos.md)):

| Carga | Potencia | Horas/día | kWh/mes | Fuente del dato |
|---|---|---|---|---|
| Bomba NFT 12 V (a través del cargador) | 40 W | 24 | ≈ 29 + pérdidas del cargador | 960 Wh/día en la fuente |
| Luces T8 8 × 18 W | 144 W | 12–14 | 52–60 (≈ $60–90/mes) | [02-restricciones](../referencia/02-restricciones-y-requisitos.md), bom/fase1 |
| Bomba de riego 12 V (ciclos de nebulización) | 40–80 W | ≈ 4 [POR VERIFICAR: sumar ciclos reales en HA] | 5–10 | estimación |
| Refrigerador de cosecha (usado, 9–11 pies) | — | — | 25–40 | nota de bom/fase2 |
| Cerebro (mini PC) + router + UPS | ≈ 15–30 W [POR VERIFICAR: medir] | 24 | 11–22 | estimación |
| 2 nodos ESP32 + sensores | ≈ 1–2 W c/u [POR VERIFICAR: medir] | 24 | 1.5–3 | estimación |
| Ventilador 12 V, tapete térmico (dic–feb) | [POR VERIFICAR: ficha del producto elegido] | — | — | — |
| **Total huerto (sin ventilador ni tapete)** | | | **≈ 125–165 kWh/mes** | |

Si el recibo actual de la casa ya ronda los 100 kWh/mes, el huerto la deja pegada al umbral DAC: por eso la bomba periférica de 370 W (~$260/mes) se descarta y la sumergible de 65 W (~$45/mes) o la de diafragma de 12 V son las únicas opciones sensatas ([02-restricciones §5](../referencia/02-restricciones-y-requisitos.md)).

## Lista de protecciones

| # | Protección | Dónde | Valor | Qué evita |
|---|---|---|---|---|
| 1 | Breaker GFCI Square D QO120GFI (o contacto GFCI Square D) | centro de carga / aguas arriba del patio | 20 A, dispara con ~5 mA | electrocución con manos mojadas |
| 2 | Tierra física: varilla copperweld 5/8" × 3 m + conductor 8 AWG | tablero → registro en el patio | ≤ 25 Ω medidos | equipo energizado sin camino de falla |
| 3 | Contacto WR con tapa "in-use" + clavija SJT uso rudo | patio | 15/20 A | lluvia y riego sobre el contacto |
| 4 | Gabinete A (CA) y gabinete B (CC) IP65 con prensaestopas, separados | patio | IP65 | goteo sobre fuentes/relés; mezcla 127 V–12 V |
| 5 | Fusible principal F0 ANL/MIDI | ≤ 30 cm del borne + de la batería | 30 A | cortocircuito del cable de batería (incendio) |
| 6 | Seccionador S1 | entre batería y bus | 30 A | trabajar con el bus vivo |
| 7 | Fusiblera de 6 vías | gabinete B | F1/F2 10 A bombas · F3 2 A nodo · F4 5 A dosificación · F5 2 A reserva | cada rama protege su cable |
| 8 | Fusibles del nodo de riego | gabinete B (Fase 1) | F0 5 A fuente · F1 5 A bomba · F2 2 A ventilador · F3 1 A bobina K5 · F5 2 A luces (127 V) | ídem |
| 9 | Diodo Schottky D1 1N5822 | entrada del buck | — | polaridad invertida al conectar la batería |
| 10 | C1/C2/C3, C5/C6, C4 en EN | alimentación del ESP32 | 100 µF · 470 µF · 100 nF · 10 µF · 100 nF | reinicios por huecos de tensión |
| 11 | TVS SMBJ15A (opcional) | entrada 12 V del nodo | 15 V | picos de la bomba y solenoides |
| 12 | Diodo flyback 1N5819 por canal MOSFET | driver de peristálticas y solenoides | — | picos inductivos que matan el MOSFET |
| 13 | Pull-down 10 kΩ en GPIO12 | nodo NFT | 10 kΩ | ESP32 que no arranca |
| 14 | Divisores 10k/20k en ECHO y YF-S201; RC 1 kΩ/100 nF en ADC | entradas | — | 5 V en un pin de 3.3 V; ruido en las sondas |
| 15 | BMS interno de la LiFePO4 | batería | corte por bajo voltaje | descarga profunda |
| 16 | K1 por contacto NC + `restore_mode: RESTORE_DEFAULT_ON` | bus DC / firmware | — | bomba parada por un reinicio o un nodo muerto |
| 17 | Watchdog "bomba ON sin flujo" (YF-S201) → K2 respaldo + alerta crítica | Home Assistant | < 2 L/min por 2 min | bomba tapada o línea rota ([06-validacion](../referencia/06-validacion-y-lazos-agenticos.md)) |
| 18 | Solenoides NC; interlock "sin dosificación si nivel bajo o bomba apagada" | firmware | — | vaciar el tinaco; dosificar en seco |
| 19 | UPS DataShield DS-600 para router + cerebro | casa | 600 VA | quedarse sin alertas durante el corte |
| 20 | Prueba mensual: botar el breaker del patio 10 min | operación | — | descubrir en el apagón real que algo no funcionaba |

Normativa (nivel divulgativo, no asesoría legal): NOM-001-SEDE-2012, texto en el DOF citado en [research/electrico-respaldo-seguridad.md §4](../research/electrico-respaldo-seguridad.md) y resumido en [Normativa](../referencia/normativa.md). Numeración de artículos (210-8 GFCI en exteriores, 406 lugares mojados, 110-11 equipo apto, 250 puesta a tierra) [POR VERIFICAR: confirmar numeración exacta en el texto del DOF]. Separación mínima entre dos varillas de tierra [POR VERIFICAR: Art. 250 de la NOM-001].

## Errores típicos

!!! warning "Sensores en ADC2"
    Los capacitivos leen bien en la mesa y "se vuelven locos" al conectar Wi-Fi: estaban en GPIO0/2/4/12–15/25–27 (ADC2). Solo ADC1 (GPIO32–39) para analógicos.

!!! warning "GPIO12 alto en el arranque"
    El nodo NFT arranca en la mesa pero no en campo: el módulo relé activo en bajo o el cable largo dejan GPIO12 alto al encender. Pull-down de 10 kΩ y driver MOSFET; o mueve el solenoide a GPIO19 (o a GPIO16/17 si no usas los flotadores del tambo).

!!! warning "Buck sin ajustar"
    El LM2596 sale de fábrica con la salida cerca de la entrada (≈ 12 V). Ajústalo a 5.0 V con multímetro **antes** de conectar el ESP32; si no, es un ESP32 menos.

!!! warning "USB y VIN a la vez"
    Flashear por USB con el buck conectado alimenta dos fuentes contra el mismo riel. Primer flasheo en la mesa por USB; en campo, todo por OTA.

!!! warning "Relés alimentados del 3V3"
    Cuatro bobinas de 5 V (~0.3 A) del 3V3 del ESP32 reinician el nodo cada vez que arranca la bomba. VCC y JD-VCC del módulo al 5 V del buck.

!!! warning "GND por el cable de señal"
    El retorno de la bomba pasa por el negro del sensor y las lecturas saltan al encenderla. Cada carga regresa por su propio cable a la barra de tierra en estrella.

!!! warning "Conector del capacitivo hacia abajo"
    Los sensores capacitivos mueren por corrosión del conector, no del sensor: conector hacia arriba, sellado con esmalte o epóxica, y el pack de 10 tiene 20–30 % de piezas malas ([research/electronica-automatizacion.md](../research/electronica-automatizacion.md)).

!!! warning "ECHO o YF-S201 directo al GPIO"
    Ambos entregan 5 V. Sin divisor 10k/20k el pin aguanta unos días y luego deja de leer.

!!! warning "Batería sin fusible en el borne"
    Un cable de 10 AWG en corto contra una LiFePO4 de 100 Ah se pone rojo antes de que el BMS reaccione. F0 de 30 A a ≤ 30 cm del borne positivo, siempre.

!!! warning "Quitar el GFCI porque dispara"
    Dispara porque hay fuga: una fuente goteada, un cable pelado en el tinaco, un contacto sin tapa. Se busca la fuga con el circuito desenergizado; nunca se puentea.

!!! warning "127 V y 12 V en el mismo gabinete"
    Un cable de 127 V suelto sobre la fusiblera de 12 V se lleva los dos nodos y, si hay agua, a la persona. Gabinete A y gabinete B, prensaestopas separados.

!!! warning "Confiar en Home Assistant para que corra el agua"
    Si la bomba depende de una automatización, un router reiniciado mata el cultivo. K1 por contacto NC: HA avisa y optimiza; la continuidad es física.

!!! warning "Solenoide NO en vez de NC"
    Con un solenoide normalmente abierto, el corte de luz vacía el tinaco al NFT. Solo válvulas NC.

!!! warning "Alargar el cable del electrodo de pH"
    El electrodo es de altísima impedancia: cada metro extra de coaxial suma ruido y deriva. La placa pH va a menos de un metro del retorno; lo que se alarga es el cable de 3.3 V al ESP32.

!!! warning "Puente neutro–tierra en el patio"
    Unir N y T en el contacto del patio hace que el GFCI dispare "sin razón" y que el neutro cargue la tierra. El puente existe solo en el centro de carga principal.

## Al terminar

- [ ] Los 5 SVG abren en el navegador y coinciden con lo que hay dentro de los gabinetes (fotos en la bitácora).
- [ ] Tabla de pines igual en `firmware/esphome/*.yaml`, en los scripts de `hardware/electrico/` y en esta página.
- [ ] Electricista entregó por escrito: valor de tierra (≤ 25 Ω), modelo del breaker GFCI, calibre de los conductores.
- [ ] Botón TEST del GFCI probado; simulacro de apagón de 10 min pasado (la bomba sigue, llegan 2 alertas).
- [ ] Todos los fusibles etiquetados con su valor y su rama; repuestos de cada valor en el gabinete.
- Registrar en bitácora: crea `bitacora/electrico.csv` con campos `fecha,evento,gabinete,rama,valor_medido,unidad,quien,observaciones` (eventos: `tierra_ohm`, `test_gfci`, `simulacro_apagon`, `fusible_cambiado`, `v_bateria`).
- Siguiente paso: [Flashear ESPHome](../guias/flashear-esphome.md) → [Configurar Home Assistant](../guias/configurar-home-assistant.md) → [Dry-run V3](../validacion/v03-dry-run.md). Diseño de los lazos de control en [Control](control.md); la parte hidráulica (bombas, válvulas, sondas en el circuito de agua) en [Hidráulico](hidraulico.md).

## Fuentes

- [research/electrico-respaldo-seguridad.md](../research/electrico-respaldo-seguridad.md) — dimensionamiento del respaldo, cotizaciones, NOM-001-SEDE-2012, YAML del detector de red y automatizaciones.
- [research/electronica-automatizacion.md](../research/electronica-automatizacion.md) — componentes v1/v2, proveedores y precios.
- [referencia/03-instalacion.md](../referencia/03-instalacion.md) §1.3 (alimentación y seguridad eléctrica) y §2.3 (arquitectura DC-first).
- [referencia/06-validacion-y-lazos-agenticos.md](../referencia/06-validacion-y-lazos-agenticos.md) — lazos L0 y watchdogs.
- [referencia/07-puntos-ciegos-y-riesgos.md](../referencia/07-puntos-ciegos-y-riesgos.md) y [02-restricciones-y-requisitos.md](../referencia/02-restricciones-y-requisitos.md) — tarifa DAC y consumo.
- [bom/fase1.csv y bom/fase2.csv](../referencia/bom.md) — partidas de automatización, respaldo y seguridad.
- Texto de la NOM-001-SEDE-2012 en el DOF: <https://dof.gob.mx/nota_detalle.php?codigo=5280607&fecha=29/11/2012>

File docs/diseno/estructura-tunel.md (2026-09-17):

# Estructura del túnel

**En una línea:** un túnel a dos aguas de PTR 1½" cal. 14, anclado a la losa con placas y
anclas de cuña, con pendiente de 30 %, plástico UV tensado y malla antigranizo separada 150 mm:
diseñado en Fase 1 a 3 × 6 m para crecer a 5 × 6 m en Fase 2 sin tirar nada.

!!! info "Antes de empezar"
    - **Tiempo:** 20 min de lectura; la construcción se reparte en 4 semanas (colchón 6) en
      [Fase 1 · Túnel](../fases/fase-1/tunel.md). · **Costo:** estructura DIY 3 × 6 m
      ≈ $10,700–15,300 todo incluido; ampliación a 5 × 6 m ≈ $15,300–21,500
      ([research/estructura-invernadero.md](../research/estructura-invernadero.md)). ·
      **Personas:** tú + herrero (2–4 días) + 2 ayudantes el día del plástico.
    - **Necesitas:** las listas de [compras Fase 1](../fases/fase-1/compras.md) y
      [Fase 2](../fases/fase-2/compras.md) (o el [BOM por fase](../referencia/bom.md)),
      rotomartillo ½", broca de concreto 3/8", llave 9/16", nivel, hilo y escuadra
      ([04-herramientas](../referencia/04-herramientas.md)).
    - **Prerequisitos:** [Antes de gastar un peso](../empieza-aqui/antes-de-gastar-un-peso.md)
      (¿el patio es tuyo o de condominio? ¿se puede perforar la losa?),
      [Layout del patio](layout-patio.md) (dónde va el túnel respecto a coladeras, tinaco y acceso).

## Vista general

Cinco reglas gobiernan el diseño; todo lo demás (cortes, anclas, pendientes) sale de ellas:

1. **El enemigo es la succión del viento, no el peso.** Un túnel de 18 m² con plástico es una
   vela de ~20 m²; las rachas de tormenta en CDMX llegan a 50–80 km/h. Se ancla SIEMPRE, con
   placas y anclas de cuña, y se triangula con contravientos
   ([research/instalacion-tunel-detalle.md §1](../research/instalacion-tunel-detalle.md)).
2. **Pendiente ≥ 25 % a dos aguas.** El granizo y el agua tienen que escurrir; las bolsas de
   agua/hielo son la causa #1 de colapso del plástico. Aquí: 30 %.
3. **Malla antigranizo 10–20 cm por encima del plástico** (aquí 150 mm), como segunda piel
   sobre postes cortos. El pico estadístico de granizo es agosto: no se desmonta temprano
   ([02-restricciones](../referencia/02-restricciones-y-requisitos.md)).
4. **Largueros por la cara interior** de cabios y columnas para que ninguna arista roce el
   plástico; plástico tensado al mediodía con perfil zigzag; cortinas laterales enrollables.
5. **La canaleta nace con la estructura:** canalón de PVC en cada alero con 0.5–1 % de
   pendiente hacia la bajante y el tinaco ([hidraulico.md §3](hidraulico.md)).

```mermaid
flowchart LR
    T[Día 0 · Trazo y croquis<br/>2–3 h, tú] --> H[Taller · Herrero corta, suelda<br/>placas y pinta · 2–4 días]
    H --> A[Montaje 1 · Anclas y esqueleto<br/>1 día, herrero + tú]
    A --> C[Montaje 2 · Plástico y mallas<br/>medio día, 3 personas, mediodía sin viento]
    C --> K[Canalón y bajante al tinaco<br/>tú]
    K --> R[Re-tensado al 3er día<br/>y prueba con manguera]
    style A fill:#fff7ed,stroke:#b45309
    style C fill:#fff7ed,stroke:#b45309
    style R fill:#f0fdf4,stroke:#2e7d32
```

| Modelo | Qué decide | Render | Archivo OpenSCAD |
|---|---|---|---|
| Túnel 3 × 6 m | Geometría, cortes y anclaje de Fase 1 | [`tunel-3x6.png`](../assets/diagramas/cad/tunel-3x6.png) | [`hardware/cad/tunel_3x6.scad`](https://github.com/AndresIslas99/HomeGreen/blob/main/hardware/cad/tunel_3x6.scad) |
| Túnel 5 × 6 m | Ampliación de Fase 2 con el mismo módulo | [`tunel-5x6.png`](../assets/diagramas/cad/tunel-5x6.png) | [`hardware/cad/tunel_5x6.scad`](https://github.com/AndresIslas99/HomeGreen/blob/main/hardware/cad/tunel_5x6.scad) |
| Patio Fase 2 | Cómo cabe todo en los 80 m² | [`patio-fase-2-3d.png`](../assets/diagramas/cad/patio-fase-2-3d.png) | [`hardware/cad/patio_fase2.scad`](https://github.com/AndresIslas99/HomeGreen/blob/main/hardware/cad/patio_fase2.scad) |

Los modelos son paramétricos: cambias `ancho`, `largo`, `n_porticos` o `pendiente` al
principio del archivo y el modelo imprime la nueva lista de cortes en consola. Cómo
modificarlos y re-renderizar: [`hardware/cad/README.md`](https://github.com/AndresIslas99/HomeGreen/blob/main/hardware/cad/README.md).

---

## 1. Geometría del túnel 3 × 6 m (Fase 1)

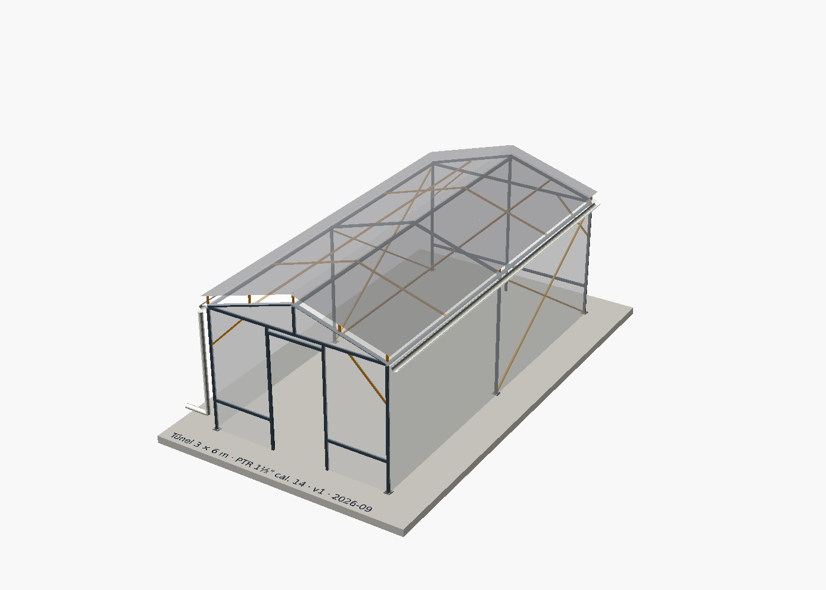
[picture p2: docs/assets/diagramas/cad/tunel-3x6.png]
Render 3D del túnel 3 × 6 m: 6 columnas de PTR 1½" con placas base, cabios a dos aguas, cumbrera, largueros, cruz de San Andrés en ámbar, plástico translúcido, malla antigranizo separada, canalón y bajante; puerta en la cabecera norte


**Cómo leerlo.** Gris oscuro = PTR 1½" (estructura principal); ámbar = PTR 1" (cabios
intermedios, largueros de techo, contravientos, postes de la malla); superficie blanca
translúcida = plástico UV cal. 720; gris translúcido superior = malla antigranizo a 150 mm;
media caña blanca en cada alero = canalón de PVC con bajante en la esquina noreste (hacia el
tinaco). La puerta va en la cabecera norte porque el acceso del patio se supone al norte
([layout-patio.md](layout-patio.md)).

| Parámetro | Valor | Por qué / fuente |
|---|---|---|
| Ancho × largo (exterior) | 3.0 × 6.0 m (18 m²) | Rango 15–20 m² de Fase 1 ([00-plan-maestro](../referencia/00-plan-maestro.md)) |
| Pórticos / columnas | 3 pórticos, 6 columnas, a 3.0 m | "Túnel 6 columnas, 24 anclas" del informe de anclaje; entre pórticos va un **cabio intermedio** de PTR 1" a 1.5 m para que el plástico no se pandee |
| Altura de alero (columna) | 2.00 m | Rango 2.2–2.4 m de altura total del informe de estructura; alero a 2.0 m deja pasar racks de 1.83 m |
| Pendiente del techo | 30 % (16.7°) → peralte 0.45 m | Mínimo 25 % ([03-instalacion §1.1](../referencia/03-instalacion.md)) |
| Altura de cumbrera (eje) | 2.49 m | Calculada: 2.00 + 0.04 (alero) + 0.45 |
| Cabio (corte) | 1.586 m | Calculado por el modelo (hipotenusa + un perfil de traslape) |
| Perfil principal | PTR 1½" × 1½" cal. 14 (38 mm, pared 1.9 mm) | [Sodimac $403; $382.85 con 5+ piezas](https://www.sodimac.com.mx/sodimac-mx/product/433713/ptr-1-1-2x1-1-2-calibre-14/433713) |
| Perfil ligero | PTR 1" × 1" (25 mm) | Largueros ligeros y contravientos ([bom/fase1.csv](../referencia/bom.md)) |
| Puerta | 0.90 × 1.90 m, cabecera norte, jambas + dintel + pendolón | Corrediza, abatible o traslape de malla: las 3 opciones están en la guía de Hydro Environment |
| Travesaños de cabecera | uno bajo (rodapié a 0.50 m) y uno alto (a la altura del alero) | Secuencia de armado §2, paso 9 del informe |
| Contravientos | 1 cruz de San Andrés por fachada larga (primera crujía) + 4 escuadras a 45° en esquinas | "Sin esto el marco se paralelogramea con la primera racha" ([research/estructura-invernadero.md](../research/estructura-invernadero.md)) |
| Malla antigranizo | 150 mm sobre el plástico, sobre postes cortos de PTR 1" y alambre galvanizado | 10–20 cm de separación; cristal/monofilamento HDPE |
| Canalón | PVC ~11 cm en cada alero, 0.75 % hacia la bajante 3" | 0.5–1 % ([research/instalacion-tunel-detalle.md §4](../research/instalacion-tunel-detalle.md)) |

!!! tip "¿Postes cada 3 m o cada 2 m?"
    [03-instalacion §1.1](../referencia/03-instalacion.md) pide "postes cada ≤ 2 m"; el informe
    de anclaje presupuesta 6 columnas (3 m). El modelo concilia ambas cosas con cabios
    intermedios sin columna cada 1.5 m. Si tu herrero prefiere columnas cada 2 m, pon
    `n_porticos = 4` en `tunel_3x6.scad`: son 2 columnas, 8 anclas y ~1 tramo más de PTR.

## 2. Ampliación a 5 × 6 m (Fase 2)

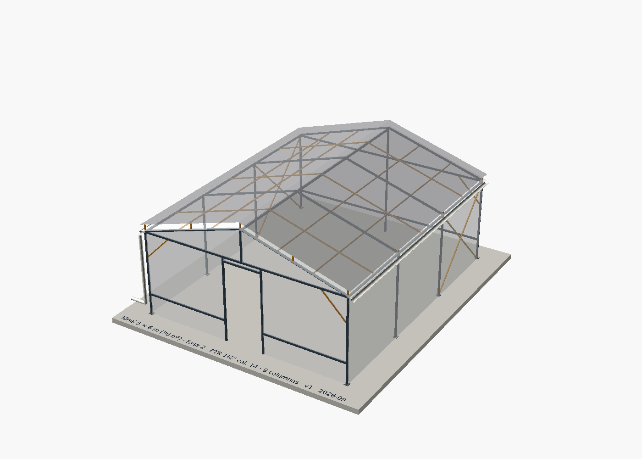
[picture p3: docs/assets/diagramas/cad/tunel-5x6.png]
Render 3D del túnel 5 × 6 m: 8 columnas, cabios de 2.6 m, dos largueros de techo por agua, misma puerta al norte, canalón y malla antigranizo


El mismo módulo `tunel()` con `ancho = 5000`, `n_porticos = 4` y `largueros_techo = 2`. Se
ensancha, no se alarga: la cumbrera, los largueros de alero, las 6 columnas, la puerta y sus
placas/anclas se reutilizan; se agregan 2 columnas (claros de 2 m, como pide
[03-instalacion](../referencia/03-instalacion.md)), cabios nuevos de 2.63 m y una cabecera más
ancha. Los cabios viejos de 1.59 m sirven como escuadras o largueros cortos.

| Parámetro | 3 × 6 m (Fase 1) | 5 × 6 m (Fase 2) |
|---|---|---|
| Superficie | 18 m² | 30 m² |
| Columnas / anclas | 6 / 24 | 8 / 32 |
| Separación entre pórticos | 3.0 m (+ cabio intermedio a 1.5 m) | 2.0 m (+ cabio intermedio a 1.0 m) |
| Peralte / cumbrera (eje) | 0.45 m / 2.49 m | 0.75 m / 2.79 m |
| Cabio | 1.59 m | 2.63 m |
| Largueros intermedios de techo | 1 por agua | 2 por agua |
| Tirantes de la cruz de San Andrés | 3.50 m | 2.72 m |
| PTR 1½" (metros lineales) | 58.0 m | 82.1 m (+24.1 m) |
| PTR 1" (metros lineales) | 38.3 m | 57.5 m (+19.2 m) |
| Techo que capta lluvia (2 aguas) | 2 × 1.55 × 6 ≈ 18.6 m² → ~19 L por mm de lluvia | 2 × 2.61 × 6 ≈ 31 m² → ~31 L por mm |

Con una tormenta de 30 mm el techo de Fase 1 manda ~560 L al tinaco de 750 L y el de Fase 2
~940 L (aritmética con 1 mm = 1 L/m²; el informe da 500–600 L para 15–20 m²): el rebosadero
del tinaco a la coladera no es opcional ([hidraulico.md §3](hidraulico.md)).

## 3. Lista de cortes de PTR

Las listas las imprime el modelo (`ECHO` de OpenSCAD) con los parámetros de arriba; las
longitudes son de eje a eje **más un perfil de traslape** en los cabios. Pide al herrero que
las confirme sobre el trazo real antes de cortar (uniones a tope, sin cartabones) y que
agregue 1–2 cm por pieza si va a escuadrar en campo.

=== "3 × 6 m (Fase 1)"

    | Pieza | Perfil | Cantidad | Longitud |
    |---|---|---|---|
    | Columna | PTR 1½" | 6 | 2,000 mm |
    | Cabio a dos aguas | PTR 1½" | 6 | 1,586 mm |
    | Cumbrera | PTR 1½" | 1 | 6,000 mm |
    | Larguero de alero | PTR 1½" | 2 | 6,000 mm |
    | Travesaño alto de cabecera | PTR 1½" | 2 | 2,924 mm |
    | Travesaño bajo (rodapié) cabecera sur | PTR 1½" | 1 | 2,924 mm |
    | Travesaño bajo cabecera norte (partido por la puerta) | PTR 1½" | 2 | 974 mm |
    | Poste central cabecera sur | PTR 1½" | 1 | 2,450 mm |
    | Jamba de puerta | PTR 1½" | 2 | 2,000 mm |
    | Dintel de puerta | PTR 1½" | 1 | 900 mm |
    | Pendolón cabecera norte | PTR 1½" | 1 | 412 mm |
    | Cabio intermedio (arco sin columna) | PTR 1" | 4 | 1,586 mm |
    | Larguero intermedio de techo | PTR 1" | 2 | 6,000 mm |
    | Tirante de cruz de San Andrés (fachadas largas) | PTR 1" | 4 | 3,500 mm |
    | Escuadra de esquina a 45° (cabeceras) | PTR 1" | 4 | 849 mm |
    | Poste de malla antigranizo | PTR 1" | 15 | 170 mm |
    | **Total PTR 1½"** | | 25 piezas | **58.0 m** |
    | **Total PTR 1"** | | 29 piezas | **38.3 m** |

    Placas base: 6 de 100 × 100 mm (solera 3/16"–¼") con 4 barrenos de 7/16". Anclas de cuña
    3/8" × 5": 24.

=== "5 × 6 m (Fase 2)"

    | Pieza | Perfil | Cantidad | Longitud |
    |---|---|---|---|
    | Columna | PTR 1½" | 8 (6 reutilizadas + 2) | 2,000 mm |
    | Cabio a dos aguas | PTR 1½" | 8 | 2,630 mm |
    | Cumbrera | PTR 1½" | 1 (reutilizada) | 6,000 mm |
    | Larguero de alero | PTR 1½" | 2 (reutilizados) | 6,000 mm |
    | Travesaño alto de cabecera | PTR 1½" | 2 | 4,924 mm |
    | Travesaño bajo cabecera sur | PTR 1½" | 1 | 4,924 mm |
    | Travesaño bajo cabecera norte (partido) | PTR 1½" | 2 | 1,974 mm |
    | Poste central cabecera sur | PTR 1½" | 1 | 2,750 mm |
    | Jamba de puerta | PTR 1½" | 2 (reutilizadas) | 2,000 mm |
    | Dintel de puerta | PTR 1½" | 1 (reutilizado) | 900 mm |
    | Pendolón cabecera norte | PTR 1½" | 1 | 712 mm |
    | Cabio intermedio (arco sin columna) | PTR 1" | 6 | 2,630 mm |
    | Larguero intermedio de techo | PTR 1" | 4 (2 reutilizados) | 6,000 mm |
    | Tirante de cruz de San Andrés | PTR 1" | 4 | 2,721 mm |
    | Escuadra de esquina a 45° | PTR 1" | 4 (reutilizadas) | 849 mm |
    | Poste de malla antigranizo | PTR 1" | 20 (15 reutilizados) | 170 mm |
    | **Total PTR 1½"** | | 29 piezas | **82.1 m** |
    | **Total PTR 1"** | | 38 piezas | **57.5 m** |

    Placas base: 8 (2 nuevas). Anclas de cuña 3/8" × 5": 32 (8 nuevas).
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

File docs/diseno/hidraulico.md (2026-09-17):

# Diseño hidráulico

**En una línea:** tres circuitos de agua —riego de microgreens, NFT recirculante y captación
pluvial— que comparten un solo principio: **todo corre desde el tinaco propio, nunca de la toma
directa**, y la recirculación del NFT cuelga de un bus de 12 V con batería, no de la red ni de
Home Assistant.

!!! info "Qué decide esta página"
    - **Diámetros, caudales, pendientes y volúmenes** de los tres circuitos, con el número y su fuente.
    - **Tags de instrumentos** (LT-1, FT-1, AT-1…) que usan los esquemas eléctricos
      ([electrico.md](electrico.md)), el firmware y las automatizaciones ([control.md](control.md)).
    - **Secuencias de llenado y purga** que se repiten en operación (cambio de solución cada 2–3
      semanas, purga del tlaloque tras cada tormenta).
    - Dónde va cada cosa en el patio: [layout-patio.md](layout-patio.md).
    - Los tres P&ID se generan con `hardware/hidraulico/pid.py` (solo Python estándar); si cambias un
      diámetro o un tag, cámbialo ahí y regenera.
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

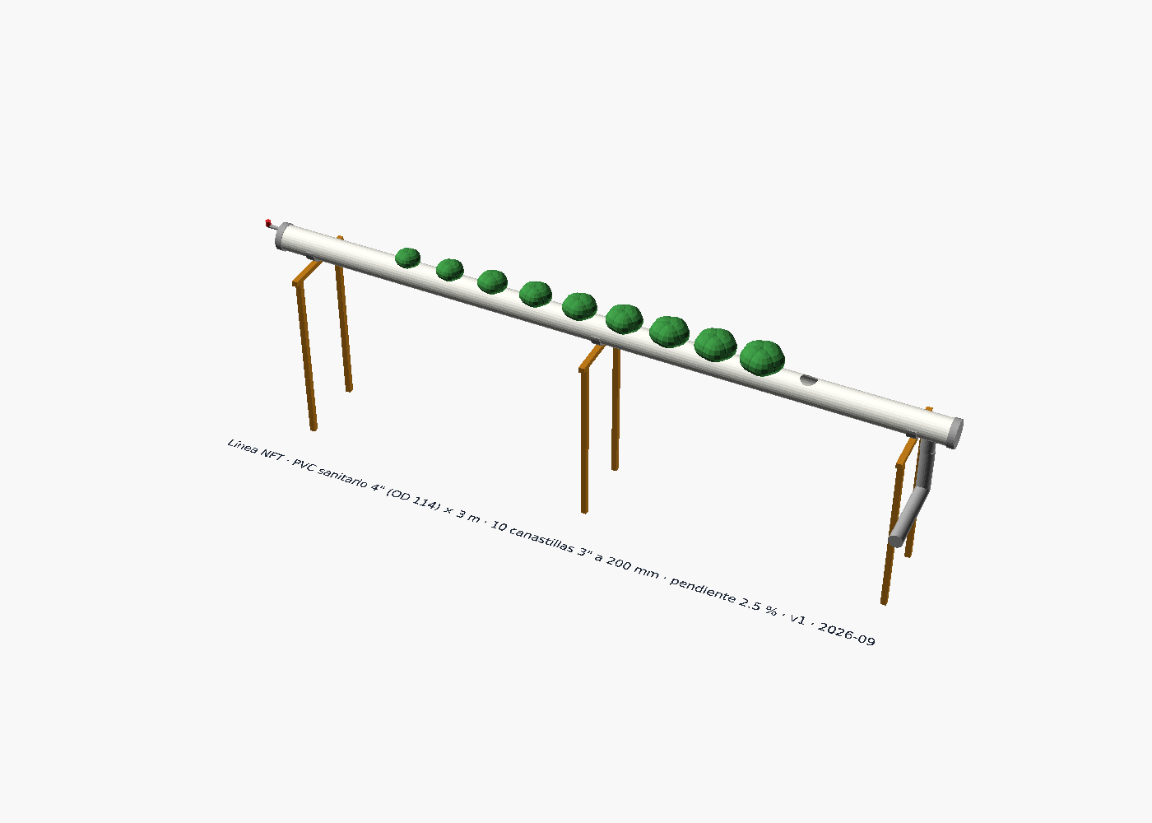
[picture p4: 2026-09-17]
docs/assets/diagramas/cad/linea-nft.png

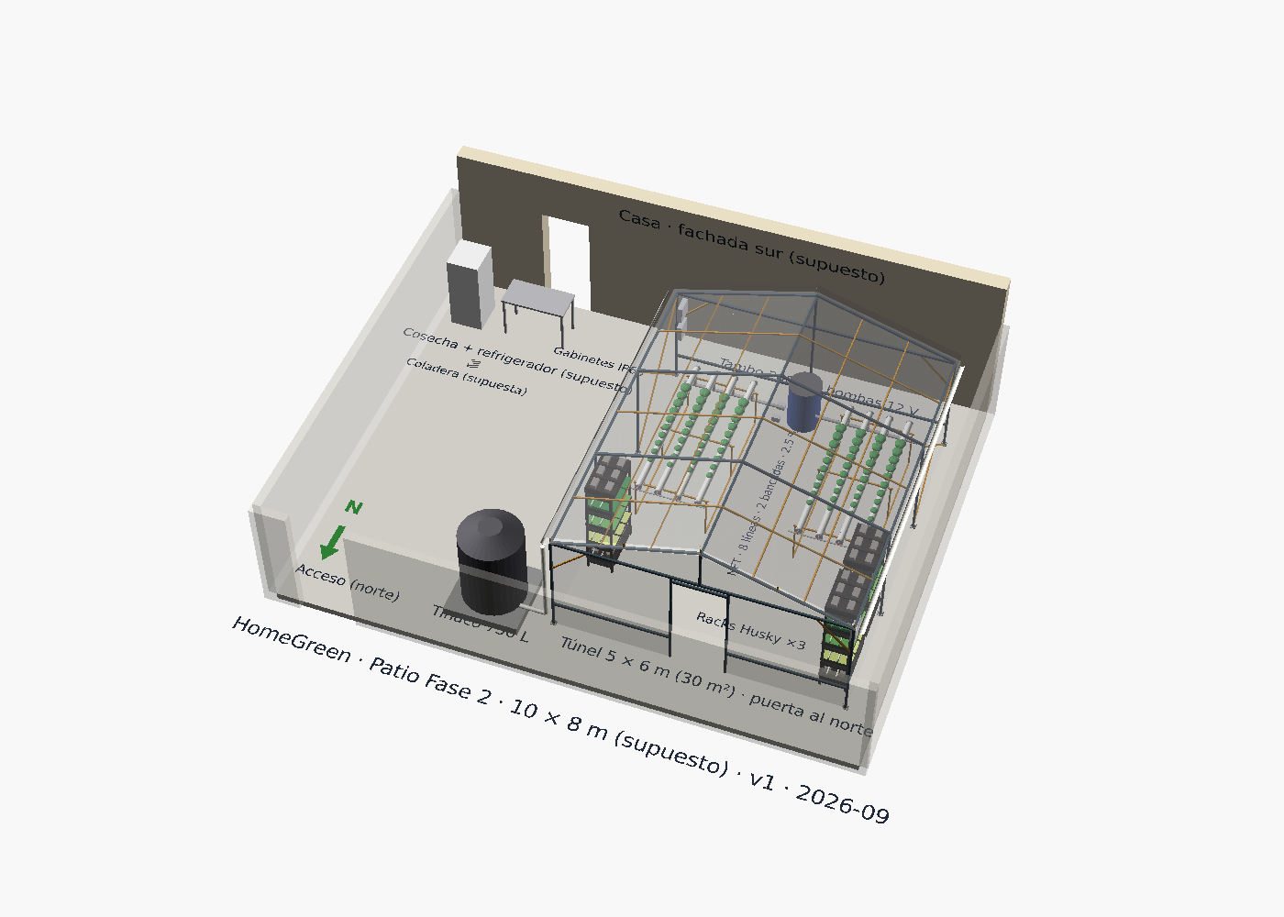
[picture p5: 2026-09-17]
docs/assets/diagramas/cad/patio-fase-2-3d.png

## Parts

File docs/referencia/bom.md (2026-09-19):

# BOM por fase

Lista de materiales del proyecto. **Una fila = una cosa que se compra una vez.**
Las alternativas de proveedor no viven aquí: viven en
[`bom/opciones.csv`](https://github.com/AndresIslas99/HomeGreen/blob/main/bom/opciones.csv),
que **no tiene columna de subtotal** y por lo tanto no puede inflar ningún total.

!!! info "Cómo leer esta página"
    - **Las partidas en *cursiva*, con el subtotal entre paréntesis, no suman.**
      Siguen aquí porque son información útil (un precio de referencia, una compra
      condicional, algo que ya pagaste en la fase anterior), pero el total de la fase
      no las incluye. La razón de cada una está en su nota y en la tabla de abajo.
    - **El subtotal siempre es `cantidad × precio unitario`.**
      [`tools/gen_bom.py`](https://github.com/AndresIslas99/HomeGreen/blob/main/tools/gen_bom.py)
      falla si alguna fila no multiplica, así que no puede volver a desalinearse.
    - **El precio es el de la opción marcada como predeterminada.** Cambiar de
      proveedor es cambiar `opcion_default` y volver a correr el script: el total
      se recalcula solo.
    - Para comprar **en persona**, la ruta en auto está en
      [Proveedores presenciales](proveedores-presenciales.md).

## Resumen

| Fase | Inversión que sí se desembolsa | Versión austera |
|---|---:|---:|
| Fase 0 · Validación comercial | $8,814 | $8,095 |
| Fase 1 · Túnel y automatización v1 | $41,634 | $40,244 |
| Fase 2 · NFT y automatización v2 | $27,251 | $24,082 |
| **Acumulado Fases 0–2** | **$77,699** | **$72,421** |

La columna austera cambia cada partida a la opción marcada como
`alternativa_austera` en `opciones.csv` (rack Adir en vez de Husky, contacto GFCI en vez
de breaker, batería AGM en vez de LiFePO4, plástico de invernaderosMX). **La calcula el
script**, así que no puede desfasarse como la frase suelta que traía el CSV viejo, que
afirmaba que comprar 250 g de rábano salía más barato que 500 g cuando el escalón de
precio lo encarece $200.

??? warning "Qué cambió respecto del BOM viejo, y por qué el total bajó"
    El BOM anterior publicaba **$86,500** acumulados. Este publica **$77,699**.
    La diferencia no es que se haya recortado el proyecto: es que el total viejo
    cobraba cosas dos veces o cobraba alternativas entre las que hay que elegir una. Son $12,138 repartidos en 8 filas que ahora siguen visibles pero en cero:

    | Partida | Importe | Por qué no suma |
    |---|---:|---|
    | Separador de primeras lluvias (Paquete Basico Tlaloc) | $5,300 | misma función que una partida ya pagada antes |
    | Electricista certificado | $2,500 | misma función que una partida ya pagada antes |
    | No-break del cerebro y el router | $1,189 | misma función que una partida ya pagada antes |
    | Breaker GFCI del circuito del patio | $1,159 | misma función que una partida ya pagada antes |
    | Tapa intemperie + varilla copperweld + cable cal. 8 | $900 | misma función que una partida ya pagada antes |
    | Responsabilidad civil PyMEs con RC de productos | $500 | gasto mensual, no inversión de capital |
    | Chicharo Early Perfection a granel | $340 | precio de referencia; el propio proyecto dice que no se compra |
    | Hipoclorito de calcio 65% (estandar duro 20,000 ppm) | $250 | solo si se da el supuesto que la nota describe |

## Fase 0 · Validación comercial

**Total de la fase: $8,814**

| Partida | Cant. | P. unitario | Subtotal | Dónde comprarla | Notas |
|---|---:|---:|---:|---|---|
| Rack de produccion 5 niveles (183x91x46 cm) | 1 pza | $2,019 | $2,019 | Home Depot Copilco *(+2 opc.)* | 362.9 kg/repisa. Forrar entrepanos con plastico o charola colectora |
| Charola 10x20 PERFORADA (la de adentro del par) | 10 pza | $60 | $600 | Al Natural *(+1 opc.)* | Flujo de doble charola: la perforada va DENTRO de la lisa. Se compran juntas, 10 pares |
| Charola 10x20 LISA (la de afuera: riego por fondo y blackout) | 10 pza | $60 | $600 | Al Natural *(+1 opc.)* | NO es duplicado de la perforada: es la otra mitad del par. Tambien sirve de tapa para la oscuridad |
| Girasol: prueba A/B de semilla (juego de 2 lotes de 1 kg) | 1 juego | $219 | $219 | Central de Abasto *(+1 opc.)* | NO son dos compras del mismo insumo: es UN experimento. 3 charolas gemelas de cada lote. Si el de CEDA germina >=80% en V1, la recompra es costal d… |
| *Chicharo Early Perfection a granel* | 1 kg | $340 | — *($340)* | Central de Abasto | NO COMPRAR. A $340/kg y 275 g por charola son $93.50 de semilla: pierde dinero. Conseguir arvejon grado alimento en CEDA (~$40-60/kg) antes de semb… |
| Rabano Champion a granel | 500 g | $2 | $800 | Hydro Environment *(+1 opc.)* | Rinde 25-30 g por charola. SIEMPRE comprar 500 g: el escalon de 453+ g cuesta $1.60/g contra $4.00/g de 100-452 g. Comprar 250 g para ahorrar SALE … |
| Betabel Early Wonder a granel | 500 g | $2 | $800 | Hydro Environment *(+1 opc.)* | Ciclo mas largo que el rabano: sembrar menos volumen. Mismo escalon de precio que el rabano |
| Brocoli para brotes | 1 bolsa | $201 | $201 | Central de Abasto *(+1 opc.)* | NO comprar en Hydro Environment: $3,500/kg. Confirmar gramaje de la bolsa antes de pagar |
| Variedades finas para muestras (amaranto, mostaza, cilantro) | 3 sobre | $100 | $300 | Ignacio Allende 21 *(+1 opc.)* | Solo muestras a chefs. Pasar a granel cuando haya pedido recurrente |
| Polvillo de coco para germinacion 50 L | 2 pza | $115 | $230 | Hydro Environment *(+2 opc.)* | ~$2.10 por charola. Al escalar: tarima de 20 blocks lavados |
| Bascula de cosecha 1 g (hasta 5-10 kg) | 1 pza | $120 | $120 | Steren Miguel Angel de Quevedo *(+1 opc.)* | Pesa la cosecha y arma pedidos. NO puede hacer el trabajo de la de dosificacion |
| Bascula de dosificacion 0.1 g (hasta 500 g) | 1 pza | $180 | $180 | Steren Miguel Angel de Quevedo *(+1 opc.)* | Dosifica semilla por charola y despues sales A/B. NO puede hacer el trabajo de la de cosecha |
| Tijera recta de acero inoxidable | 1 pza | $90 | $90 | Costco Coapa | Mejor que tijera de jardin para microgreens |
| Atomizador 1 L | 2 pza | $80 | $160 | Home Depot Copilco | Son 2 a proposito: uno queda EXCLUSIVO para H2O2 y etiquetado. Mezclarlos contamina el agua de riego |
| Guantes de nitrilo (caja 100) | 1 caja | $250 | $250 | Home Depot Copilco *(+2 opc.)* |  |
| Sanitizante de semilla y charolas (H2O2 35% grado alimenticio) | 1 L | $200 | $200 | Cerrada de Colima 2 *(+2 opc.)* | Se diluye 1:11 para llegar a 3%: 1 L rinde ~11 L de solucion de trabajo. DILUIR SIEMPRE |
| Agua oxigenada 3% de farmacia (puente del dia 1) | 2 pza | $30 | $60 | Farmacias del Ahorro/Guadalajara | Es el puente mientras llega el H2O2 al 35%. No es duplicado: es la presentacion lista para usar del dia 1 |
| *Hipoclorito de calcio 65% (estandar duro 20,000 ppm)* | 1 kg | $250 | — *($250)* | Cualquier super de Coyoacan *(+1 opc.)* | Solo si un cliente hotelero o corporativo exige el estandar duro. 31 g/L 15 min + triple enjuague |
| Clamshell PET 8 oz | 100 pza | $4 | $350 | Reno 45 *(+2 opc.)* | Al escalar, cotizar fabricante |
| Etiquetas adhesivas (tiraje chico) | 300 pza | $2 | $600 | Jose Maria Bustillos 19-A *(+1 opc.)* | Marca + variedad + fecha de cosecha + lote + contacto. El lote es lo que hace posible un recall |
| Termometro de cocina | 1 pza | $150 | $150 | Steren Miguel Angel de Quevedo *(+1 opc.)* | Doble uso: precalentado a 60 C para sanitizar semilla y registro de cadena de frio en entregas |
| Microgreens: The Insiders Secrets (Donny Greens) | 1 pza | $397 | $397 | **solo en línea** *(+1 opc.)* | El libro de VENDER a chefs. Leer antes de las visitas |
| El jardinero horticultor (Fortier) | 1 pza | $488 | $488 | El Pendulo *(+1 opc.)* | Siembras escalonadas y canal directo |

## Fase 1 · Túnel y automatización v1

**Total de la fase: $41,634**

| Partida | Cant. | P. unitario | Subtotal | Dónde comprarla | Notas |
|---|---:|---:|---:|---|---|
| PTR 1.5x1.5 pulg cal. 14 x 6 m (porticos del tunel) | 15 tramo | $383 | $5,743 | Sodimac Gran Sur *(+3 opc.)* | Tunel 3x6 m a dos aguas. Disenar empalmes desde ahora para poder ampliar a 5x6 en Fase 2 |
| PTR 1 pulg (largueros y contravientos) | 4 tramo | $275 | $1,100 | Sodimac Gran Sur *(+1 opc.)* | POR VERIFICAR ANTES DE LA S7: docs/diseno/estructura-tunel.md calcula 7 tramos con kerf, no 4. Si son 7, esta partida sube a $1,925 (+$825) |
| Herreria: soldadura, primario y tornilleria | 1 servicio | $2,000 | $2,000 | Pedir referencias en el mostrador de Perfiles Pacifico o Aceros Mixcoac | Pedir 3 cotizaciones POR ESCRITO. El herrero trae su equipo, asi evitas comprar esmeriladora y careta |
| Anclaje: placas base 10x10 + anclas de cuna 3/8 x 3 | 6 juego | $180 | $1,080 | Home Depot Coapa del Hueso *(+1 opc.)* | 2-4 anclas por placa sobre firme de concreto. NUNCA sin anclar: hay rachas de 50-80 km/h. El subtotal viejo decia $1,100 y la multiplicacion da $1,080 |
| Plastico UV cal. 720 blanco lechoso 25% sombra, 6.2 m de ancho | 8 m | $215 | $1,720 | Hydro Environment *(+2 opc.)* | Blanco lechoso, no transparente: difunde la luz y baja el golpe de calor |
| Malla antigranizo 3.7 m de ancho | 40 m | $40 | $1,600 | Hydro Environment *(+1 opc.)* | Va montada 10-20 cm SOBRE el plastico, no pegada. Instalar antes de mayo: el pico estadistico de granizo es agosto |
| Perfil zigzag + resorte + cinta reparadora + canaleta PVC | 1 lote | $1,100 | $1,100 | Hydro Environment *(+2 opc.)* | La canaleta nace con la estructura: es la que alimenta la captacion pluvial |
| Racks de produccion ADICIONALES (3 mas: total 4 con el de Fase 0) | 3 pza | $2,019 | $6,057 | Home Depot Copilco *(+1 opc.)* | NO es recompra: el rack de Fase 0 se muda al tunel y estos 3 amplian capacidad. El recorte austero compra 2 y deja 3 en total |
| Tinaco de almacenamiento 750 L | 1 pza | $2,051 | $2,051 | Home Depot Coapa del Hueso *(+2 opc.)* | Sombreado u opaco. Si tu alcaldia tiene tandeo duro, subir a 1,100 L |
| Separador de primeras lluvias + filtro de hojas | 1 sistema | $1,500 | $1,500 | Ferreteria Copilco / Home Depot Coyoacan *(+3 opc.)* | DECIDIR UNA SOLA VEZ, antes de gastar: si aplicas a Cosecha de Lluvia de SEDEMA en enero-febrero y calificas, NO compres ninguna de las dos. El DIY… |
| ESP32 DevKit V1 30 pines | 3 pza | $130 | $390 | UNIT Electronics Copilco *(+1 opc.)* | 2 nodos + 1 de repuesto. El repuesto no es lujo: es lo que evita parar una semana |
| Sensor de temperatura y humedad ambiente | 2 pza | $91 | $182 | UNIT Electronics Copilco *(+2 opc.)* | Upgrade sobre el DHT22: no deriva con la humedad alta sostenida del tunel |
| DS18B20 sumergible | 3 pza | $35 | $105 | UNIT Electronics Copilco *(+1 opc.)* | Comprar 3: es el sensor que mas se maltrata |
| Sensor capacitivo de humedad de sustrato | 6 pza | $26 | $156 | UNIT Electronics Copilco *(+2 opc.)* | 20-30% salen malos de fabrica. Comprando en mostrador puedes revisarlos antes de pagar, por eso 6 y no 10. Sellar el borde del PCB con esmalte y mo… |
| Modulo rele 4 canales optoacoplado | 2 pza | $110 | $220 | UNIT Electronics Copilco *(+1 opc.)* | Riego + ventilador + luces + reserva |
| Fuente 12 V 5 A del circuito critico | 1 pza | $399 | $399 | Steren Miguel Angel de Quevedo *(+2 opc.)* |  |
| Bomba de nebulizacion del rack (diafragma 12 V con presostato) | 1 pza | $350 | $350 | Hydro Environment *(+2 opc.)* | Da presion para nebulizar, 4-6 L/min. NO es la misma bomba que la de recirculacion NFT de Fase 2 |
| Kit de nebulizadores / microaspersores | 1 kit | $250 | $250 | Hydro Environment *(+1 opc.)* | 10-30 boquillas con manguera |
| Sensor de nivel del tinaco (JSN-SR04T) | 1 pza | $150 | $150 | UNIT Electronics Copilco *(+1 opc.)* | Zona muerta de ~20 cm por encima del nivel maximo: montarlo con esa holgura |
| Cerebro (servidor de Home Assistant) | 1 pza | $3,000 | $3,000 | AG Electronica *(+2 opc.)* | Corre Home Assistant + Grafana. Si ademas quieres Frigate para vision, el mini PC rinde mas que la Pi |
| No-break del cerebro y el router | 1 pza | $900 | $900 | Steren Miguel Angel de Quevedo *(+2 opc.)* | Sin internet no hay alarmas. Esta partida NO se vuelve a comprar en Fase 2: es la misma |
| Gabinete IP65 ~300x300x90 + prensaestopas | 2 pza | $350 | $700 | Home Depot Coapa del Hueso *(+1 opc.)* | Uno para el nodo del tunel y otro para el nodo de bomba |
| Material de soporte: cable, borneras, fusibles, termofit, cinchos | 1 lote | $1,000 | $1,000 | AG Electronica *(+2 opc.)* | Comprar en persona y de paso conocer al proveedor de emergencia del mismo dia |
| Tubo LED T8 18 W 120 cm 6500 K | 8 pza | $121 | $968 | Home Depot Copilco *(+2 opc.)* | 2 por nivel. NO pagar grow lights para un ciclo de 10 dias: no se amortizan |
| Canaletas y cable para los tubos T8 | 1 lote | $400 | $400 | Home Depot Copilco *(+1 opc.)* | PARTIDA NUEVA: las notas del BOM viejo la mencionaban y ningun renglon la sumaba |
| Tapete termico de germinacion | 1 pza | $380 | $380 | **solo en línea** | CUESTIONA ESTA PARTIDA ANTES DE COMPRARLA: en CDMX, para girasol, chicharo y rabano, la germinacion bajo blackout con charolas apiladas suele basta… |
| Malla sombra 35% 3.7 m de ancho | 6 m | $129 | $774 | Hydro Environment *(+2 opc.)* | SOLO de marzo a mayo, por el UV extremo. Se quita el resto del ano: la albahaca de Fase 2 necesita luz. Si tu S12 no cae en marzo-mayo, difierela |
| Jabon potasico 1 kg | 1 kg | $250 | $250 | Mercado de Cuemanco / El Chino *(+2 opc.)* | Pulgon, mosca blanca y trips: 10-15 ml/L aplicado al enves de la hoja |
| Trampas amarillas pegajosas | 1 paquete | $150 | $150 | Mercado de Cuemanco / El Chino *(+1 opc.)* | Una por rack. Es el indicador temprano mas barato que existe |
| Bti para mosca fungosa (Gnatrol DG o equivalente) | 1 pza | $800 | $800 | Av. Guadalupe I. Ramirez *(+1 opc.)* | Comprar ANTES de la primera temporada de lluvias, no cuando ya hay mosca |
| Herramienta de Fase 1 (rotomartillo, brocas, taquetes, niveles) | 1 lote | $1,600 | $1,600 | Home Depot Copilco *(+1 opc.)* | Si suelda el herrero, no hace falta esmeriladora ni careta |
| Breaker GFCI del circuito del patio | 1 pza | $1,159 | $1,159 | Home Depot Coapa del Hueso *(+1 opc.)* | MOVIDA DESDE EL BOM DE FASE 2: docs/fases/fase-1/compras.md la exige en la S13, antes del primer rele en el patio. Estaba presupuestada en las dos … |
| Tapa intemperie in-use + varilla copperweld 5/8 x 3 m + cable cal. 8 | 1 lote | $900 | $900 | Home Depot Coapa del Hueso | MOVIDA DESDE EL BOM DE FASE 2. NOM-001: un patio es lugar mojado. Tierra <=25 ohms MEDIDOS, no supuestos |
| Electricista certificado (GFCI, tierra fisica y contacto exterior) | 1 servicio | $2,500 | $2,500 | Pedir referencias en Electrica Evolucion (Col. Espartaco | MOVIDA DESDE EL BOM DE FASE 2. Pedir 3 cotizaciones. Medio dia a dia, llave en mano $1,500-3,500 |

## Fase 2 · NFT y automatización v2

**Total de la fase: $27,251**

| Partida | Cant. | P. unitario | Subtotal | Dónde comprarla | Notas |
|---|---:|---:|---:|---|---|
| Tubo PVC SANITARIO 4 pulg x 6 m (lineas NFT) | 4 tramo | $415 | $1,660 | Home Depot Coapa del Hueso | SANITARIO, no hidraulico cedula 40 ($1,401): el NFT corre sin presion y la diferencia es 3.4x. Blanco porque refleja el calor |
| Codos 90/45, tapas y adaptadores de drenaje 4 pulg | 1 lote | $600 | $600 | Home Depot Coapa del Hueso | Codo de 90 $28.80, codo de 45 $18.31 |
| Tuberia de distribucion 1/2-3/4, retorno 2 pulg y valvulas de compuerta por linea | 1 lote | $750 | $750 | Home Depot Coapa del Hueso *(+1 opc.)* | Caudal objetivo 1-2 L/min por linea: se mide con botella de 1 L y cronometro |
| Cemento para PVC, limpiador, teflon y lima de desbarbar | 1 lote | $280 | $280 | Home Depot Coapa del Hueso *(+1 opc.)* | PARTIDA NUEVA: las notas del BOM viejo la mencionaban y ningun renglon la sumaba. Sin desbarbar, el borde corta la raiz |
| Canastilla hidroponica 3 pulg | 80 pza | $13 | $1,024 | Hydro Environment *(+2 opc.)* | COMPRARLAS ANTES DE PERFORAR. Medir el cuerpo bajo el labio para elegir la sierra copa |
| Sierra copa bimetalica del diametro medido + mandril | 1 pza | $300 | $300 | Home Depot Copilco *(+1 opc.)* | UN SOLO diametro, el que midas de la canastilla. Tipico 44-48 mm para canastilla de 2 pulg; aqui es de 3 pulg, asi que MIDE |
| Bomba de llenado, purga y trasiego (sumergible 4500 LPH) | 1 pza | $1,199 | $1,199 | Hydro Environment *(+1 opc.)* | 65 W (~$45/mes de luz) contra 370 W de una periferica (~$260/mes). NO es la bomba de recirculacion 24/7: esa es de 12 V y cuelga de la bateria |
| Filtro de malla 120 mesh 1 pulg | 1 pza | $230 | $230 | Hydro Environment *(+1 opc.)* | Va en el RETORNO, antes de la bomba |
| Deposito de solucion nutritiva 200 L grado alimenticio | 1 pza | $700 | $700 | Home Depot Coapa del Hueso *(+1 opc.)* | Bajo sombra. La solucion ideal va a 18-22 C. Cambio completo cada 2-3 semanas |
| Semillero de foami agricola 144 bloques | 2 pza | $46 | $91 | Hydro Environment *(+1 opc.)* | $0.32 por planta. NO usar peat pellets: tapan el filtro |
| Solucion nutritiva para hortalizas (rinde 1,000 L) | 2 pza | $349 | $698 | Hydro Environment *(+2 opc.)* | Al pasar de 2 m3/mes conviene el costal de 25 kg ($202/m3) o sales A/B ($90-150/m3). DESCARTAR Flora Series GHE: cuesta 10-40x |
| Acido regulador pH- AquAcid (REACTIVO de dosificacion) | 1 pza | $516 | $516 | Hydro Environment *(+2 opc.)* | Es el reactivo que dosifica la peristaltica para bajar el pH de la solucion. NO confundir con los estandares de calibracion, que son otra cosa aunq… |
| Estandar de calibracion pH 4.01 | 2 pza | $40 | $80 | **solo en línea** *(+1 opc.)* | ESTANDAR DE CALIBRACION, no toca el cultivo. Calibracion quincenal, con evento programado en Home Assistant |
| Estandar de calibracion pH 6.86 (o 7.01) | 1 botella | $150 | $150 | HANNA: Vainilla 462 *(+2 opc.)* | El segundo punto de la calibracion. 6.86 y 7.01 son dos estandares distintos pero equivalentes para este uso: usa el que consigas |
| Solucion de calibracion EC 1413 uS/cm | 1 pza | $459 | $459 | Vainilla 462 *(+2 opc.)* | Caducidad de 5 anos cerrada. Presupuesto anual de calibracion mas sonda: ~$1,050 |
| Sonda de pH del deposito NFT | 1 pza | $318 | $318 | UNIT Electronics Copilco *(+2 opc.)* | Etapa 1: valida el lazo de control. El kit DFRobot NO se compra hasta que el NFT facture: su electrodo caduca a los 12-18 meses aunque siga en la caja |
| Sonda EC/TDS FIJA del retorno (SEN0244) | 1 pza | $253 | $253 | UNIT Electronics Copilco *(+1 opc.)* | Es la sonda fija que lee ESPHome, montada en el RETORNO. No confundir con el medidor de mano, que es el arbitro |
| Bombas peristalticas 12 V (A, B, pH- y repuesto) | 4 pza | $225 | $900 | **solo en línea** *(+1 opc.)* | La manguera interna es consumible: se reemplaza, no se repara |
| Valvula solenoide 12 V 1/2 NC | 2 pza | $128 | $256 | UNIT Electronics Copilco *(+1 opc.)* | NC (normalmente cerrada): un corte de luz NO vacia el tinaco |
| ESP32-CAM OV2640 | 1 pza | $260 | $260 | UNIT Electronics Copilco *(+1 opc.)* | Timelapse e inspeccion remota |
| Sensor de flujo YF-S201 | 1 pza | $64 | $64 | UNIT Electronics Copilco *(+1 opc.)* | Watchdog de bomba tapada o linea rota |
| *Separador de primeras lluvias (Paquete Basico Tlaloc)* | 1 sistema | $5,300 | — *($5,300)* | **solo en línea** | NO SUMA: es la MISMA funcion que la partida F1-010, que ya se decidio y se pago en Fase 1. Si en Fase 1 elegiste el DIY de $1,500 y ahora quieres e… |
| Filtro duplex de sedimento 5 um + carbon activado 10 pulg | 1 juego | $1,000 | $1,000 | Home Depot Coapa del Hueso *(+1 opc.)* | Solo en la linea que llena el deposito NFT: quita el cloro. Los CARTUCHOS son consumible cada 4-6 meses, no compra unica |
| Medidor de mano pH + EC (arbitro de calibracion) | 1 pza | $450 | $450 | Vainilla 462 *(+2 opc.)* | Es el ARBITRO: con el operas en manual las primeras semanas y con el detectas que la sonda fija se descalibro. No sustituye a la sonda fija ni al r… |
| Semilla de albahaca para el NFT | 1 oz | $549 | $549 | Ignacio Allende 21 *(+1 opc.)* | Nufar es resistente a fusarium, que es el riesgo tecnico #3 del plan. Estaba AGOTADA al 12-sep-2026: si no hay reabasto, cambia a la opcion Genoves… |
| Cultivos hidroponicos (Resh, 5a ed. en espanol) | 1 pza | $899 | $899 | El Pendulo Coyoacan (pedido) *(+1 opc.)* | Comprar con los ingresos de Fase 1. Es el porque de las bandas de pH y EC |
| Bateria LiFePO4 12.8 V 100 Ah | 1 pza | $4,459 | $4,459 | Solar Center: Av. Central 154 *(+3 opc.)* | 28-30 h de recirculacion continua. Es el corazon de la arquitectura DC-first: un apagon no mata el NFT |
| Bombas de recirculacion NFT 24/7 DC (principal + respaldo) | 2 pza | $650 | $1,300 | Hydro Environment *(+2 opc.)* | ARQUITECTURA DC-FIRST: la bomba del NFT que corre 24/7 es de 12 V y cuelga del bus de bateria. La de 127 V solo hace llenado y purga. POR VERIFICAR… |
| Controlador de carga solar (cargador de la LiFePO4) | 1 pza | $599 | $599 | Vallejo (Solar Center *(+1 opc.)* | Requisito duro: que tenga perfil LiFePO4 configurable |
| Panel solar 100 W | 1 pza | $1,049 | $1,049 | Abaco Solaris: Calle de America 173-1 *(+1 opc.)* | Opcional pero recomendado: flota la bateria sin CFE. Un corte diurno se vuelve sostenible indefinidamente |
| Fusiblera 12 V, seccionador DC y gabinete del bus | 1 lote | $700 | $700 | AutoZone y Steren en Coyoacan; el seccionador DC en Vallejo *(+1 opc.)* | PARTIDA NUEVA: las notas del BOM viejo la estimaban en $500-900 y ningun renglon la sumaba |
| Envio de las partidas que no tienen mostrador (panel, bateria) | 1 lote | $158 | $158 | **solo en línea** | PARTIDA NUEVA: el envio del panel aparecia en las notas y nunca se sumaba. Si compras presencial en Vallejo o Coyoacan, esta partida se va a cero |
| *No-break del cerebro y el router* | 1 pza | $1,189 | — *($1,189)* | — | NO SUMA: es la misma funcion que F1-021, ya comprada. Solo se recompra si el de Fase 1 no sostiene 45 min con el cerebro y el modem. Comprobalo con… |
| *Breaker GFCI del circuito del patio* | 1 pza | $1,159 | — *($1,159)* | — | NO SUMA: movida a F1-032. El proyecto la exige en la S13 de Fase 1, antes de energizar el primer rele del patio. Estaba presupuestada en las dos fases |
| *Tapa intemperie + varilla copperweld + cable cal. 8* | 1 lote | $900 | — *($900)* | — | NO SUMA: movida a F1-033 |
| *Electricista certificado* | 1 servicio | $2,500 | — *($2,500)* | — | NO SUMA: movida a F1-034 |
| Refrigerador 9-11 pies (producto cortado a 4-5 C) | 1 pza | $4,000 | $4,000 | Home Depot Coapa del Hueso *(+2 opc.)* | Cortado a 20-25 C dura menos de un dia; a 5 C dura 14. Suma 25-40 kWh/mes al calculo de la tarifa DAC: metelo en la cuenta antes de comprarlo |
| Hielera rigida 45-50 L + 6 gel packs (reparto) | 1 juego | $1,300 | $1,300 | Home Depot Coapa del Hueso *(+1 opc.)* | Pre-enfriar el producto la noche anterior. Objetivo: menos de 10 C durante 4-6 h de ruta |
| *Responsabilidad civil PyMEs con RC de productos* | 1 poliza | $500 | — *($500)* | Agentes en CDMX | NO SUMA AL TOTAL DE INVERSION porque es un gasto RECURRENTE (~$500/mes, $3,000-8,000/ano), no capital. Solo cuando entre un cliente corporativo u h… |

## Archivos fuente

| Archivo | Qué es |
|---|---|
| [`bom/partidas.csv`](https://github.com/AndresIslas99/HomeGreen/blob/main/bom/partidas.csv) | Las 96 partidas. Una fila = una compra. |
| [`bom/opciones.csv`](https://github.com/AndresIslas99/HomeGreen/blob/main/bom/opciones.csv) | Las 206 opciones de proveedor. Sin subtotal: no puede inflar nada. |
| [`tools/gen_bom.py`](https://github.com/AndresIslas99/HomeGreen/blob/main/tools/gen_bom.py) | Valida la aritmética y regenera esta página. |

De las 96 partidas, **86 tienen al menos una opción con mostrador físico**.

<!-- Generado por tools/gen_bom.py. No editar a mano: los cambios van en los CSV. -->

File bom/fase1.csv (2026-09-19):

partida_id | bloque | categoria | partida | cantidad | unidad | precio_unit_mxn | subtotal_mxn | cuenta_en_total | motivo_si_no_cuenta | proveedor_default | tienda_fisica | sucursal_o_zona | enlace | opciones_de_proveedor | temporada | notas
F1-001 | S7-dia1 | estructura | PTR 1.5x1.5 pulg cal. 14 x 6 m (porticos del tunel) | 15 | tramo | 382.85 | 5742.75 | si |  | Sodimac | si | Sodimac Gran Sur, Periferico Sur 5550, Coyoacan | https://www.sodimac.com.mx/sodimac-mx/product/433713/ptr-1-1-2x1-1-2-calibre-14/433713 | 4 |  | Tunel 3x6 m a dos aguas. Disenar empalmes desde ahora para poder ampliar a 5x6 en Fase 2
F1-002 | S7-dia1 | estructura | PTR 1 pulg (largueros y contravientos) | 4 | tramo | 275 | 1100 | si |  | Sodimac / Perfiles Pacifico | si | Sodimac Gran Sur, Periferico Sur 5550, Coyoacan / Perfiles Pacifico, Coyoacan | https://www.sodimac.com.mx/sodimac-mx/category/cat11448/PTR | 2 |  | POR VERIFICAR ANTES DE LA S7: docs/diseno/estructura-tunel.md calcula 7 tramos con kerf, no 4. Si son 7, esta partida sube a $1,925 (+$825)
F1-003 | S7 | estructura | Herreria: soldadura, primario y tornilleria | 1 | servicio | 2000 | 2000 | si |  | Herrero local | si | Pedir referencias en el mostrador de Perfiles Pacifico o Aceros Mixcoac |  | 1 |  | Pedir 3 cotizaciones POR ESCRITO. El herrero trae su equipo, asi evitas comprar esmeriladora y careta
F1-004 | S7 | estructura | Anclaje: placas base 10x10 + anclas de cuna 3/8 x 3 | 6 | juego | 180 | 1080 | si |  | Home Depot / tlapaleria | si | Home Depot Coapa del Hueso, Calz. del Hueso 670, Coyoacan / Ferreteria Copilco, Av. A. Delfin Madrigal 137 | https://www.homedepot.com.mx/s/taquete | 2 |  | 2-4 anclas por placa sobre firme de concreto. NUNCA sin anclar: hay rachas de 50-80 km/h. El subtotal viejo decia $1,100 y la multiplicacion da $1,080
F1-005 | S8 | cubierta | Plastico UV cal. 720 blanco lechoso 25% sombra, 6.2 m de ancho | 8 | m | 215 | 1720 | si |  | Hydro Environment | si | Hydro Environment, Av. Toltecas 41, Tlalnepantla | https://hydroenv.com.mx/producto/metro-de-plastico-para-invernadero-25-sombra-6-2-m-de-ancho-cal-720/ | 3 |  | Blanco lechoso, no transparente: difunde la luz y baja el golpe de calor
F1-006 | S8 | cubierta | Malla antigranizo 3.7 m de ancho | 40 | m | 40 | 1600 | si |  | Capi Agricola | no | Texcoco, Edo. Mex. (60 km, direccion contraria) | https://www.capiagricola.com.mx/product/malla-antigranizo-negra-3-70-m-x-metro/ | 2 | antes de mayo | Va montada 10-20 cm SOBRE el plastico, no pegada. Instalar antes de mayo: el pico estadistico de granizo es agosto
F1-007 | S8 | cubierta | Perfil zigzag + resorte + cinta reparadora + canaleta PVC | 1 | lote | 1100 | 1100 | si |  | Hydro Environment | si | Hydro Environment, Av. Toltecas 41, Tlalnepantla | https://hydroenv.com.mx/plastico-para-invernadero-y-campo/ | 3 |  | La canaleta nace con la estructura: es la que alimenta la captacion pluvial
F1-008 | S9 | racks | Racks de produccion ADICIONALES (3 mas: total 4 con el de Fase 0) | 3 | pza | 2019 | 6057 | si |  | Home Depot | si | Home Depot Copilco, Eje 10 #546, Coyoacan | https://www.homedepot.com.mx/p/husky-estante-de-5-niveles-de-acero-183-x-914-x-457-cm-negro-zrop361872-5llb-150281 | 2 |  | NO es recompra: el rack de Fase 0 se muda al tunel y estos 3 amplian capacidad. El recorte austero compra 2 y deja 3 en total
F1-009 | S10 | agua | Tinaco de almacenamiento 750 L | 1 | pza | 2051 | 2051 | si |  | Home Depot | si | Home Depot Coapa del Hueso, Calz. del Hueso 670, Coyoacan | https://rotoplas.com.mx/products/almacenamiento/tinacos/ | 3 |  | Sombreado u opaco. Si tu alcaldia tiene tandeo duro, subir a 1,100 L
F1-010 | S10 | agua | Separador de primeras lluvias + filtro de hojas | 1 | sistema | 1500 | 1500 | si |  | Tlapaleria + manual gratuito | si | Ferreteria Copilco / Home Depot Coyoacan | https://www.engineeringforchange.org/wp-content/uploads/2020/07/MANUAL-INSTALACI%C3%93N-KIT-TL%C3%81LOC-12-JUNIO-2019CH.pdf | 4 |  | DECIDIR UNA SOLA VEZ, antes de gastar: si aplicas a Cosecha de Lluvia de SEDEMA en enero-febrero y calificas, NO compres ninguna de las dos. El DIY de Fase 1 se tira a la basura cuando llega el kit de Fase 2. El precio del kit de Isla Urbana esta POR CONFIRMAR en tienda
F1-011 | S11 | automatizacion | ESP32 DevKit V1 30 pines | 3 | pza | 130 | 390 | si |  | UNIT Electronics | si | UNIT Electronics Copilco, Av. Copilco 357, Coyoacan | https://uelectronics.com/producto/esp32-devkit-v1-30-pines-usb-c-microusb/ | 2 |  | 2 nodos + 1 de repuesto. El repuesto no es lujo: es lo que evita parar una semana
F1-012 | S11 | automatizacion | Sensor de temperatura y humedad ambiente | 2 | pza | 91 | 182 | si |  | UNIT Electronics | si | UNIT Electronics Copilco, Av. Copilco 357, Coyoacan | https://uelectronics.com | 3 |  | Upgrade sobre el DHT22: no deriva con la humedad alta sostenida del tunel
F1-013 | S11 | automatizacion | DS18B20 sumergible | 3 | pza | 35 | 105 | si |  | UNIT Electronics | si | UNIT Electronics Copilco, Av. Copilco 357, Coyoacan | https://uelectronics.com/producto/ds18b20-sensor-de-temperatura-digital-de-acero-inoxidable-sumergible/ | 2 |  | Comprar 3: es el sensor que mas se maltrata
F1-014 | S11 | automatizacion | Sensor capacitivo de humedad de sustrato | 6 | pza | 26 | 156 | si |  | UNIT Electronics | si | UNIT Electronics Copilco, Av. Copilco 357, Coyoacan | https://uelectronics.com | 3 |  | 20-30% salen malos de fabrica. Comprando en mostrador puedes revisarlos antes de pagar, por eso 6 y no 10. Sellar el borde del PCB con esmalte y montar el conector hacia arriba
F1-015 | S11 | automatizacion | Modulo rele 4 canales optoacoplado | 2 | pza | 110 | 220 | si |  | UNIT Electronics | si | UNIT Electronics Copilco, Av. Copilco 357, Coyoacan | https://uelectronics.com/producto/relevador-5v-de-1-a-8-canales/ | 2 |  | Riego + ventilador + luces + reserva
F1-016 | S11 | automatizacion | Fuente 12 V 5 A del circuito critico | 1 | pza | 399 | 399 | si |  | Steren | si | Steren Miguel Angel de Quevedo, Asia 47, Coyoacan | https://www.steren.com.mx/eliminador-regulado-de-12-vcc-5-a.html | 3
F1-017 | S11 | automatizacion | Bomba de nebulizacion del rack (diafragma 12 V con presostato) | 1 | pza | 350 | 350 | si |  | Mercado Libre | no | solo en linea | https://listado.mercadolibre.com.mx/bomba-de-agua-diafragma-12v | 3 |  | Da presion para nebulizar, 4-6 L/min. NO es la misma bomba que la de recirculacion NFT de Fase 2
F1-018 | S11 | automatizacion | Kit de nebulizadores / microaspersores | 1 | kit | 250 | 250 | si |  | Mercado Libre / Hydro Environment | si | Hydro Environment, Av. Toltecas 41, Tlalnepantla | https://listado.mercadolibre.com.mx/nebulizadores-de-riego | 2 |  | 10-30 boquillas con manguera
F1-019 | S11 | automatizacion | Sensor de nivel del tinaco (JSN-SR04T) | 1 | pza | 150 | 150 | si |  | UNIT Electronics | si | UNIT Electronics Copilco, Av. Copilco 357, Coyoacan | https://uelectronics.com/producto/sensor-ultrasonico-jns-sr04t/ | 2 |  | Zona muerta de ~20 cm por encima del nivel maximo: montarlo con esa holgura
F1-020 | S11 | automatizacion | Cerebro (servidor de Home Assistant) | 1 | pza | 3000 | 3000 | si |  | Mercado Libre | no | solo en linea / bazares de computo | https://listado.mercadolibre.com.mx/mini-pc-lenovo-thinkcentre | 3 |  | Corre Home Assistant + Grafana. Si ademas quieres Frigate para vision, el mini PC rinde mas que la Pi
F1-021 | S11 | respaldo | No-break del cerebro y el router | 1 | pza | 900 | 900 | si |  | Steren | si | Steren Miguel Angel de Quevedo, Asia 47, Coyoacan |  | 3 |  | Sin internet no hay alarmas. Esta partida NO se vuelve a comprar en Fase 2: es la misma
F1-022 | S11 | automatizacion | Gabinete IP65 ~300x300x90 + prensaestopas | 2 | pza | 350 | 700 | si |  | Home Depot / AG Electronica | si | Home Depot Coapa del Hueso, Calz. del Hueso 670, Coyoacan / AG Electronica, Rep. de El Salvador 20-F, Centro | https://listado.mercadolibre.com.mx/gabinete-plastico-exterior-ip65 | 2 |  | Uno para el nodo del tunel y otro para el nodo de bomba
F1-023 | S11 | automatizacion | Material de soporte: cable, borneras, fusibles, termofit, cinchos | 1 | lote | 1000 | 1000 | si |  | AG Electronica | si | AG Electronica, Rep. de El Salvador 20-F, Centro | https://agelectronica.com | 3 |  | Comprar en persona y de paso conocer al proveedor de emergencia del mismo dia
F1-024 | S9 | iluminacion | Tubo LED T8 18 W 120 cm 6500 K | 8 | pza | 121 | 968 | si |  | JWJ Light | no | solo en linea | https://jwjlight.mx/producto/tubo-led-t8-18w-120-cm/ | 3 |  | 2 por nivel. NO pagar grow lights para un ciclo de 10 dias: no se amortizan
F1-025 | S9 | iluminacion | Canaletas y cable para los tubos T8 | 1 | lote | 400 | 400 | si |  | Home Depot / Ferreteria Copilco | si | Home Depot Copilco, Eje 10 #546, Coyoacan |  | 2 |  | PARTIDA NUEVA: las notas del BOM viejo la mencionaban y ningun renglon la sumaba
F1-026 | S12 | clima | Tapete termico de germinacion | 1 | pza | 380 | 380 | si |  | Mercado Libre | no | solo en linea | https://listado.mercadolibre.com.mx/tapete-termico-germinacion | 1 | dic-feb | CUESTIONA ESTA PARTIDA ANTES DE COMPRARLA: en CDMX, para girasol, chicharo y rabano, la germinacion bajo blackout con charolas apiladas suele bastar. Automatizable con rele si la compras
F1-027 | S12 | clima | Malla sombra 35% 3.7 m de ancho | 6 | m | 129 | 774 | si |  | Hydro Environment | si | Hydro Environment, Av. Toltecas 41, Tlalnepantla | https://hydroenv.com.mx/producto/malla-sombra-por-metro-al-35-de-3-7-m-de-ancho/ | 3 | mar-may | SOLO de marzo a mayo, por el UV extremo. Se quita el resto del ano: la albahaca de Fase 2 necesita luz. Si tu S12 no cae en marzo-mayo, difierela
F1-028 | S12 | fitosanitario | Jabon potasico 1 kg | 1 | kg | 250 | 250 | si |  | Soluciones Naturales Pro | no | solo en linea | https://solucionesnaturalespro.com.mx/product/jabon-potasico/ | 3 |  | Pulgon, mosca blanca y trips: 10-15 ml/L aplicado al enves de la hoja
F1-029 | S12 | fitosanitario | Trampas amarillas pegajosas | 1 | paquete | 150 | 150 | si |  | El Chino / Cuemanco | si | Mercado de Cuemanco / El Chino, Xochimilco | https://listado.mercadolibre.com.mx/trampas-amarillas-pegajosas | 2 |  | Una por rack. Es el indicador temprano mas barato que existe
F1-030 | S12 | fitosanitario | Bti para mosca fungosa (Gnatrol DG o equivalente) | 1 | pza | 800 | 800 | si |  | Semillas y Agroquimicos El Chino | si | Av. Guadalupe I. Ramirez, Barrio San Marcos, Xochimilco |  | 2 | antes de lluvias | Comprar ANTES de la primera temporada de lluvias, no cuando ya hay mosca
F1-031 | S7 | herramienta | Herramienta de Fase 1 (rotomartillo, brocas, taquetes, niveles) | 1 | lote | 1600 | 1600 | si |  | Home Depot / Ferreteria Copilco | si | Home Depot Copilco, Eje 10 #546, Coyoacan |  | 2 |  | Si suelda el herrero, no hace falta esmeriladora ni careta
F1-032 | S13 | seguridad | Breaker GFCI del circuito del patio | 1 | pza | 1159 | 1159 | si |  | Home Depot | si | Home Depot Coapa del Hueso, Calz. del Hueso 670, Coyoacan | https://www.homedepot.com.mx/s/interruptor%20falla%20a%20tierra | 2 |  | MOVIDA DESDE EL BOM DE FASE 2: docs/fases/fase-1/compras.md la exige en la S13, antes del primer rele en el patio. Estaba presupuestada en las dos fases
F1-033 | S13 | seguridad | Tapa intemperie in-use + varilla copperweld 5/8 x 3 m + cable cal. 8 | 1 | lote | 900 | 900 | si |  | Home Depot / Ferreteria Copilco | si | Home Depot Coapa del Hueso, Calz. del Hueso 670, Coyoacan | https://www.homedepot.com.mx/s/tapa%20intemperie | 1 |  | MOVIDA DESDE EL BOM DE FASE 2. NOM-001: un patio es lugar mojado. Tierra <=25 ohms MEDIDOS, no supuestos
F1-034 | S13 | seguridad | Electricista certificado (GFCI, tierra fisica y contacto exterior) | 1 | servicio | 2500 | 2500 | si |  | Electricista local | si | Pedir referencias en Electrica Evolucion (Col. Espartaco, Coyoacan) |  | 1 |  | MOVIDA DESDE EL BOM DE FASE 2. Pedir 3 cotizaciones. Medio dia a dia, llave en mano $1,500-3,500

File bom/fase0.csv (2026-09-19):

partida_id | bloque | categoria | partida | cantidad | unidad | precio_unit_mxn | subtotal_mxn | cuenta_en_total | motivo_si_no_cuenta | proveedor_default | tienda_fisica | sucursal_o_zona | enlace | opciones_de_proveedor | temporada | notas
F0-001 | hoy | rack | Rack de produccion 5 niveles (183x91x46 cm) | 1 | pza | 2019 | 2019 | si |  | Home Depot | si | Home Depot Copilco, Eje 10 #546, Coyoacan | https://www.homedepot.com.mx/p/husky-estante-de-5-niveles-de-acero-183-x-914-x-457-cm-negro-zrop361872-5llb-150281 | 3 |  | 362.9 kg/repisa. Forrar entrepanos con plastico o charola colectora
F0-002 | hoy | charolas | Charola 10x20 PERFORADA (la de adentro del par) | 10 | pza | 60 | 600 | si |  | Al Natural | si | Al Natural, Torres Adalid 1957, Narvarte, Benito Juarez | https://www.alnatural.com.mx/tienda/charolas-de-germinacion-venta-mayoreo | 2 |  | Flujo de doble charola: la perforada va DENTRO de la lisa. Se compran juntas, 10 pares
F0-003 | hoy | charolas | Charola 10x20 LISA (la de afuera: riego por fondo y blackout) | 10 | pza | 60 | 600 | si |  | Al Natural | si | Al Natural, Torres Adalid 1957, Narvarte, Benito Juarez | https://www.alnatural.com.mx/tienda/charolas-de-germinacion-venta-mayoreo | 2 |  | NO es duplicado de la perforada: es la otra mitad del par. Tambien sirve de tapa para la oscuridad
F0-004 | hoy | semilla | Girasol: prueba A/B de semilla (juego de 2 lotes de 1 kg) | 1 | juego | 219 | 219 | si |  | Mayoreo Online (CEDA) + Al Natural | si | Central de Abasto, bodega A-91, Iztapalapa / Al Natural, Torres Adalid 1957, Narvarte, Benito Juarez | https://mayoreo.online/products/semilla-de-girasol-con-cascara-jumbo | 2 |  | NO son dos compras del mismo insumo: es UN experimento. 3 charolas gemelas de cada lote. Si el de CEDA germina >=80% en V1, la recompra es costal de 5 kg a $140
F0-005 | hoy | semilla | Chicharo Early Perfection a granel | 1 | kg | 340 | 0 | no | informativo | Hydro Environment | si | Hydro Environment, Av. Toltecas 41, Tlalnepantla | https://hydroenv.com.mx/producto/gramo-de-semilla-de-chicharo-variedad-early-perfection/ | 1 |  | NO COMPRAR. A $340/kg y 275 g por charola son $93.50 de semilla: pierde dinero. Conseguir arvejon grado alimento en CEDA (~$40-60/kg) antes de sembrar chicharo
F0-006 | hoy | semilla | Rabano Champion a granel | 500 | g | 1.6 | 800 | si |  | Hydro Environment | si | Hydro Environment, Av. Toltecas 41, Tlalnepantla | https://hydroenv.com.mx/producto/gramo-de-semilla-de-rabano-var-champion/ | 2 |  | Rinde 25-30 g por charola. SIEMPRE comprar 500 g: el escalon de 453+ g cuesta $1.60/g contra $4.00/g de 100-452 g. Comprar 250 g para ahorrar SALE MAS CARO
F0-007 | hoy | semilla | Betabel Early Wonder a granel | 500 | g | 1.6 | 800 | si |  | Hydro Environment | si | Hydro Environment, Av. Toltecas 41, Tlalnepantla | https://hydroenv.com.mx/producto/gramo-de-semilla-de-betabel-o-remolacha-variedad-early-wonder/ | 2 |  | Ciclo mas largo que el rabano: sembrar menos volumen. Mismo escalon de precio que el rabano
F0-008 | esta semana | semilla | Brocoli para brotes | 1 | bolsa | 201 | 201 | si |  | Hydrocultura | no | Av. Toluca 1075, Alvaro Obregon (bodega, recoleccion concertada) | https://hydrocultura.com/collections/semillas-para-microgreens-o-microvegetales | 2 |  | NO comprar en Hydro Environment: $3,500/kg. Confirmar gramaje de la bolsa antes de pagar
F0-009 | esta semana | semilla | Variedades finas para muestras (amaranto, mostaza, cilantro) | 3 | sobre | 100 | 300 | si |  | Semillas Organicas ISLA | si | Ignacio Allende 21, Miguel Hidalgo | https://semillasisla.mx/collections/microgreens | 2 |  | Solo muestras a chefs. Pasar a granel cuando haya pedido recurrente
F0-010 | hoy | sustrato | Polvillo de coco para germinacion 50 L | 2 | pza | 115 | 230 | si |  | Hydro Environment | si | Hydro Environment, Av. Toltecas 41, Tlalnepantla | https://hydroenv.com.mx/producto/polvillo-de-coco-para-germinacion-50-l-sustrato-organico/ | 3 |  | ~$2.10 por charola. Al escalar: tarima de 20 blocks lavados
F0-011 | hoy | operacion | Bascula de cosecha 1 g (hasta 5-10 kg) | 1 | pza | 120 | 120 | si |  | Steren / super | si | Steren Miguel Angel de Quevedo, Asia 47, Coyoacan |  | 2 |  | Pesa la cosecha y arma pedidos. NO puede hacer el trabajo de la de dosificacion
F0-012 | hoy | operacion | Bascula de dosificacion 0.1 g (hasta 500 g) | 1 | pza | 180 | 180 | si |  | Steren | si | Steren Miguel Angel de Quevedo, Asia 47, Coyoacan |  | 2 |  | Dosifica semilla por charola y despues sales A/B. NO puede hacer el trabajo de la de cosecha
F0-013 | hoy | operacion | Tijera recta de acero inoxidable | 1 | pza | 90 | 90 | si |  | Supermercado / Costco Coapa | si | Costco Coapa, Tlalpan |  | 1 |  | Mejor que tijera de jardin para microgreens
F0-014 | hoy | operacion | Atomizador 1 L | 2 | pza | 80 | 160 | si |  | Home Depot | si | Home Depot Copilco, Eje 10 #546, Coyoacan | https://www.homedepot.com.mx/s/atomizador | 1 |  | Son 2 a proposito: uno queda EXCLUSIVO para H2O2 y etiquetado. Mezclarlos contamina el agua de riego
F0-015 | hoy | sanidad | Guantes de nitrilo (caja 100) | 1 | caja | 250 | 250 | si |  | Farmacia / Mercado Libre | si | Farmacias de Coyoacan |  | 3
F0-016 | esta semana | sanidad | Sanitizante de semilla y charolas (H2O2 35% grado alimenticio) | 1 | L | 200 | 200 | si |  | Mercado Libre | no | solo en linea | https://listado.mercadolibre.com.mx/peroxido-de-hidrogeno-35%25-grado-alimenticio-oxigeno-liquido | 3 |  | Se diluye 1:11 para llegar a 3%: 1 L rinde ~11 L de solucion de trabajo. DILUIR SIEMPRE
F0-017 | hoy | sanidad | Agua oxigenada 3% de farmacia (puente del dia 1) | 2 | pza | 30 | 60 | si |  | Farmacia | si | Farmacias del Ahorro/Guadalajara, Coyoacan |  | 1 |  | Es el puente mientras llega el H2O2 al 35%. No es duplicado: es la presentacion lista para usar del dia 1
F0-018 | post-gate | sanidad | Hipoclorito de calcio 65% (estandar duro 20,000 ppm) | 1 | kg | 250 | 0 | no | condicional | Tienda de albercas / Mercado Libre | no | solo en linea | https://listado.mercadolibre.com.mx/hipoclorito-de-calcio | 2 |  | Solo si un cliente hotelero o corporativo exige el estandar duro. 31 g/L 15 min + triple enjuague
F0-019 | esta semana | empaque | Clamshell PET 8 oz | 100 | pza | 3.5 | 350 | si |  | Mercado Libre | no | solo en linea | https://listado.mercadolibre.com.mx/clamshell | 3 |  | Al escalar, cotizar fabricante
F0-020 | esta semana | empaque | Etiquetas adhesivas (tiraje chico) | 300 | pza | 2.0 | 600 | si |  | Dushi Imprenta | si | Jose Maria Bustillos 19-A, Algarin, Cuauhtemoc | https://www.imprentacdmx.com/servicios-de-impresion/impresion-de-etiquetas-adhesivas/ | 2 |  | Marca + variedad + fecha de cosecha + lote + contacto. El lote es lo que hace posible un recall
F0-021 | hoy | operacion | Termometro de cocina | 1 | pza | 150 | 150 | si |  | Steren / super | si | Steren Miguel Angel de Quevedo, Asia 47, Coyoacan |  | 2 |  | Doble uso: precalentado a 60 C para sanitizar semilla y registro de cadena de frio en entregas
F0-022 | esta semana | libros | Microgreens: The Insiders Secrets (Donny Greens) | 1 | pza | 396.6 | 396.6 | si |  | Amazon MX | no | solo en linea | https://www.amazon.com.mx/Microgreens-Insiders-Building-Successful-Microgreen/dp/191366600X | 2 |  | El libro de VENDER a chefs. Leer antes de las visitas
F0-023 | esta semana | libros | El jardinero horticultor (Fortier) | 1 | pza | 488 | 488 | si |  | El Pendulo | si | El Pendulo, 8 sucursales CDMX (una en Coyoacan) | https://pendulo.com/libro/jardinero-horticultor-el_393665 | 2 |  | Siembras escalonadas y canal directo

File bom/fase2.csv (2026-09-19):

partida_id | bloque | categoria | partida | cantidad | unidad | precio_unit_mxn | subtotal_mxn | cuenta_en_total | motivo_si_no_cuenta | proveedor_default | tienda_fisica | sucursal_o_zona | enlace | opciones_de_proveedor | temporada | notas
F2-001 | sem1-2 | nft | Tubo PVC SANITARIO 4 pulg x 6 m (lineas NFT) | 4 | tramo | 415 | 1660 | si |  | Home Depot | si | Home Depot Coapa del Hueso, Calz. del Hueso 670, Coyoacan | https://www.homedepot.com.mx/p/amanco-wavin-tubo-sanitario-11-x-600-cm-blanco-amanco-942842-451963 | 1 |  | SANITARIO, no hidraulico cedula 40 ($1,401): el NFT corre sin presion y la diferencia es 3.4x. Blanco porque refleja el calor
F2-002 | sem1-2 | nft | Codos 90/45, tapas y adaptadores de drenaje 4 pulg | 1 | lote | 600 | 600 | si |  | Home Depot | si | Home Depot Coapa del Hueso, Calz. del Hueso 670, Coyoacan | https://www.homedepot.com.mx/p/amanco-wavin-codo-pvc-4-513695-513695 | 1 |  | Codo de 90 $28.80, codo de 45 $18.31
F2-003 | sem1-2 | nft | Tuberia de distribucion 1/2-3/4, retorno 2 pulg y valvulas de compuerta por linea | 1 | lote | 750 | 750 | si |  | Home Depot / Ferreteria Copilco | si | Home Depot Coapa del Hueso, Calz. del Hueso 670, Coyoacan | https://www.homedepot.com.mx/b/plomeria/tuberias-y-conexiones/sanitarias | 2 |  | Caudal objetivo 1-2 L/min por linea: se mide con botella de 1 L y cronometro
F2-004 | sem1-2 | nft | Cemento para PVC, limpiador, teflon y lima de desbarbar | 1 | lote | 280 | 280 | si |  | Home Depot / Ferreteria Copilco | si | Home Depot Coapa del Hueso, Calz. del Hueso 670, Coyoacan |  | 2 |  | PARTIDA NUEVA: las notas del BOM viejo la mencionaban y ningun renglon la sumaba. Sin desbarbar, el borde corta la raiz
F2-005 | sem1-2 | nft | Canastilla hidroponica 3 pulg | 80 | pza | 12.8 | 1024 | si |  | Hydro Environment | si | Hydro Environment, Av. Toltecas 41, Tlalnepantla | https://hydroenv.com.mx/producto/canastilla-hidroponica-de-3-pulgadas/ | 3 |  | COMPRARLAS ANTES DE PERFORAR. Medir el cuerpo bajo el labio para elegir la sierra copa
F2-006 | sem1-2 | herramienta | Sierra copa bimetalica del diametro medido + mandril | 1 | pza | 300 | 300 | si |  | Home Depot | si | Home Depot Copilco, Eje 10 #546, Coyoacan | https://listado.mercadolibre.com.mx/truper-sierra-corta-circulos-bimetalica | 2 |  | UN SOLO diametro, el que midas de la canastilla. Tipico 44-48 mm para canastilla de 2 pulg; aqui es de 3 pulg, asi que MIDE
F2-007 | sem1-2 | nft | Bomba de llenado, purga y trasiego (sumergible 4500 LPH) | 1 | pza | 1199 | 1199 | si |  | Hydro Environment | si | Hydro Environment, Av. Toltecas 41, Tlalnepantla | https://hydroenv.com.mx/producto/bomba-sumergible-4500-lph-para-hidroponia-y-estanques/ | 2 |  | 65 W (~$45/mes de luz) contra 370 W de una periferica (~$260/mes). NO es la bomba de recirculacion 24/7: esa es de 12 V y cuelga de la bateria
F2-008 | sem1-2 | nft | Filtro de malla 120 mesh 1 pulg | 1 | pza | 230 | 230 | si |  | Hydro Environment | si | Hydro Environment, Av. Toltecas 41, Tlalnepantla | https://hydroenv.com.mx/producto/filtro-de-malla-para-riego-de-1-pulgada-con-salida-y-entrada-tipo-macho/ | 2 |  | Va en el RETORNO, antes de la bomba
F2-009 | sem1-2 | nft | Deposito de solucion nutritiva 200 L grado alimenticio | 1 | pza | 700 | 700 | si |  | Home Depot / Sodimac | si | Home Depot Coapa del Hueso, Calz. del Hueso 670, Coyoacan / Sodimac Gran Sur, Periferico Sur 5550, Coyoacan |  | 2 |  | Bajo sombra. La solucion ideal va a 18-22 C. Cambio completo cada 2-3 semanas
F2-010 | sem1-2 | nft | Semillero de foami agricola 144 bloques | 2 | pza | 45.5 | 91 | si |  | Hydro Environment | si | Hydro Environment, Av. Toltecas 41, Tlalnepantla | https://hydroenv.com.mx/producto/semillero-de-foami-agricola-de-144-bloques-30x30-cm/ | 2 |  | $0.32 por planta. NO usar peat pellets: tapan el filtro
F2-011 | sem3 | nutricion | Solucion nutritiva para hortalizas (rinde 1,000 L) | 2 | pza | 349 | 698 | si |  | Hydro Environment | si | Hydro Environment, Av. Toltecas 41, Tlalnepantla | https://hydroenv.com.mx/producto/solucion-nutritiva-para-hortalizas-de-1-5-kg-rinde-para-1000-litros/ | 3 |  | Al pasar de 2 m3/mes conviene el costal de 25 kg ($202/m3) o sales A/B ($90-150/m3). DESCARTAR Flora Series GHE: cuesta 10-40x
F2-012 | sem3 | nutricion | Acido regulador pH- AquAcid (REACTIVO de dosificacion) | 1 | pza | 516 | 516 | si |  | Hydro Environment | si | Hydro Environment, Av. Toltecas 41, Tlalnepantla | https://hydroenv.com.mx/producto/aquacid-buffer-para-bajar-ph-regulador-de-ph-para-hidroponia/ | 3 |  | Es el reactivo que dosifica la peristaltica para bajar el pH de la solucion. NO confundir con los estandares de calibracion, que son otra cosa aunque se llamen buffer
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

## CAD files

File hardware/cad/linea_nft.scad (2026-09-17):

// ============================================================================
//  linea_nft.scad — Línea NFT en tubo PVC SANITARIO 4" (OD 114 mm) × 3000 mm con
//  10 perforaciones para canastilla de 3", pendiente 2.5 % y soportes de PTR 1"
//  (HomeGreen · Fase 2). Modelo paramétrico OpenSCAD (2021.01). Unidades: mm.
//
//  Ejes: X = a lo largo del tubo (x = 0 es el extremo ALTO / entrada; x = L es el
//  extremo BAJO / retorno), Y = transversal, Z = altura.
//
//  ADVERTENCIA (docs/referencia/03-instalacion.md §2.1 y bom/fase2.csv): el diámetro de
//  perforación NO se toma de este archivo: se mide en el CUERPO de la canastilla comprada,
//  bajo el labio, y se prueba en un retazo. Los 70 mm de `d_perf` son solo el valor de
//  dibujo para una canastilla de 3"; una canastilla "de 2 pulgadas" pide 44–48 mm.
//  Comprar las canastillas ANTES de perforar. Desbarbar cada hoyo.
//
//  Fuentes: docs/research/hidroponia-nft.md (tubo sanitario Amanco 4" blanco $415/6 m,
//  canastilla 3" $12.80, 20 cm entre centros, pendiente 2–3 %, 1–2 L/min por línea),
//  docs/referencia/03-instalacion.md §2.1 (soportes cada ≤ 1.5 m, retorno por gravedad),
//  docs/diseno/hidraulico.md (manifold ¾" con válvula por línea, retorno 2").
//
//  Render (desde hardware/cad/):
//    xvfb-run -a openscad -o ../../docs/assets/diagramas/cad/linea-nft.png \
//      --autocenter --viewall --imgsize=1400,1000 --projection=p \
//      --colorscheme=Tomorrow --camera=0,0,0,52,0,25,0 linea_nft.scad
// ============================================================================

/* ------------------------------ Tubo ------------------------------------------- */
L_tubo     = 3000;   // media tramo de 6 m [mm]
D_tubo     = 114;    // diámetro exterior del tubo sanitario 4" [mm]
pared_tubo = 3.2;    // [mm]
n_plantas  = 10;     // perforaciones por línea
sep_perf   = 200;    // entre centros: 20 cm albahaca/arúgula (15 cm cilantro) [mm]
d_perf     = 70;     // Ø de dibujo; el real se mide en la canastilla (ver advertencia)

/* ------------------------------ Canastilla 3" ---------------------------------- */
canastilla_labio  = 82;   // Ø del labio (apoya sobre el tubo) [mm]
canastilla_cuerpo = 70;   // Ø del cuerpo bajo el labio = Ø de la sierra copa [mm] → MEDIR
canastilla_alto   = 80;   // [mm]
espuma_d          = 43;   // cilindro de foami agrícola 4.3 × 5 cm
espuma_h          = 50;

/* ------------------------------ Pendiente y soportes --------------------------- */
pendiente    = 2.5;    // % (2–3 %): 75 mm de caída en 3 m
h_eje_alto   = 900;    // altura del eje del tubo en el extremo alto [mm]
x_soportes   = [150, 1500, 2850];   // posición de los 3 soportes (≤ 1.5 m entre ellos)
soporte_a    = 25;     // PTR 1" [mm]
soporte_e    = 1.9;
pies_ancho   = 320;    // separación de las patas de un soporte de línea sencilla [mm]
cuna_esp     = 8;      // media caña que recibe el tubo [mm]

/* ------------------------------ Conexiones ------------------------------------- */
tapa_esp   = 30;   // tapa (cap) 4" [mm]
d_tapa     = 124;
entrada_d  = 16;   // manguera ½" de entrada [mm]
retorno_d  = 60;   // retorno 2" [mm]
manifold_d = 25;   // manifold de alimentación ¾" [mm]

/* ------------------------------ Qué dibujar ------------------------------------ */
mostrar_plantas   = true;
mostrar_soporte   = true;
posiciones_vacias = [9];   // índices (0..n-1) sin canastilla, para ver el barreno en el render
mostrar_titulo  = true;
$fn = 32;

/* ------------------------------ Colores ---------------------------------------- */
col_pvc      = [0.95, 0.95, 0.92];
col_pvc_gris = [0.62, 0.62, 0.62];
col_canasta  = [0.20, 0.20, 0.20];
col_espuma   = [0.45, 0.60, 0.35];
col_planta   = [0.22, 0.55, 0.25];
col_ptr1     = [0.72, 0.46, 0.09];
col_valvula  = [0.85, 0.15, 0.15];
col_texto    = [0.12, 0.16, 0.22];

/* ================================ Funciones ==================================== */
function ang_pend(p = pendiente) = atan(p / 100);
function caida(L = L_tubo, p = pendiente) = L * p / 100;
// Abscisa de la perforación i (0..n-1), centradas en el tubo
function x_perf(i, L = L_tubo, n = n_plantas, s = sep_perf) = (L - (n - 1) * s) / 2 + i * s;
// Altura del eje del tubo en la abscisa x
function z_eje(x, h0 = h_eje_alto, p = pendiente) = h0 - x * p / 100;
// ¿Está v en la lista l?
function en(v, l) = len([for (q = l) if (q == v) q]) > 0;

/* ================================ Piezas ====================================== */
// Tubo con perforaciones en la generatriz superior (eje a lo largo de +X, horizontal)
module tubo_perforado(L = L_tubo, D = D_tubo, pared = pared_tubo, n = n_plantas, s = sep_perf, dp = d_perf) {
    color(col_pvc) difference() {
        rotate([0, 90, 0]) cylinder(d = D, h = L);
        rotate([0, 90, 0]) translate([0, 0, -1]) cylinder(d = D - 2 * pared, h = L + 2);
        for (i = [0 : n - 1]) translate([x_perf(i, L, n, s), 0, 0]) cylinder(d = dp, h = D);
    }
}

// Canastilla 3" con cilindro de foami y planta (tamaño según edad 0..1)
module canastilla(edad = 1, planta = true) {
    color(col_canasta) difference() {
        union() {
            cylinder(d = canastilla_cuerpo, h = canastilla_alto);
            translate([0, 0, canastilla_alto - 3]) cylinder(d = canastilla_labio, h = 3);
        }
        translate([0, 0, 2]) cylinder(d = canastilla_cuerpo - 4, h = canastilla_alto);
        for (k = [0 : 7]) rotate([0, 0, k * 45]) translate([canastilla_cuerpo / 2 - 4, -2, 6]) cube([8, 4, canastilla_alto - 16]);
    }
    color(col_espuma) translate([0, 0, 8]) cylinder(d = espuma_d, h = espuma_h);
    if (planta) color(col_planta) translate([0, 0, canastilla_alto + 20 * edad]) scale([1, 1, 0.8])
        for (k = [0 : 4]) rotate([0, 0, k * 72]) translate([28 * edad, 0, 15 * edad]) sphere(r = 22 + 48 * edad, $fn = 16);
}

// Media caña de apoyo del tubo sobre la viga del soporte
module cuna(D = D_tubo, esp = cuna_esp, ancho = 40) {
    color(col_pvc_gris) rotate([0, 90, 0]) translate([0, 0, -ancho / 2]) difference() {
        cylinder(d = D + 2 * esp, h = ancho);
        translate([0, 0, -1]) cylinder(d = D + 2, h = ancho + 2);
        translate([-D, -D, -1]) cube([D, 2 * D, ancho + 2]);   // deja solo la mitad inferior
    }
}

// Soporte transversal: 2 patas + viga (a lo largo de Y) de PTR 1", altura de viga h
module soporte_transversal(ancho_viga = pies_ancho, h = 800, a = soporte_a, e = soporte_e) {
    color(col_ptr1) {
        for (s = [-1, 1]) translate([-a / 2, s * ancho_viga / 2 - a / 2, 0]) difference() {
            cube([a, a, h]);
            translate([e, e, -1]) cube([a - 2 * e, a - 2 * e, h + 2]);
        }
        translate([-a / 2, -ancho_viga / 2 - a / 2 - a, h - a]) cube([a, ancho_viga + 3 * a, a]);   // viga
    }
}
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

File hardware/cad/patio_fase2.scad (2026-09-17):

// ============================================================================
//  patio_fase2.scad — Composición 3D del patio en Fase 2 (HomeGreen).
//  Patio de 10 × 8 m (80 m²), casa al sur, acceso al norte — SUPUESTO de la wiki
//  (docs/diseno/layout-patio.md tiene la planta 2D acotada; si difieren, manda la planta).
//
//  Contiene: túnel 5 × 6 m (tunel_3x6.scad con otros parámetros), 8 líneas NFT en dos
//  bancadas de 4 (linea_nft.scad), tambo de 200 L (depósito de solución), tinaco de 750 L
//  (agua cruda + captación pluvial), 3 racks Husky (rack_charolas.scad), gabinetes IP65,
//  zona de cosecha con refrigerador y coladera (posición supuesta).
//
//  Unidades: mm. Ejes: X = oeste → este (0..10000), Y = sur → norte (0..8000), Z = altura.
//  Los módulos vienen por `use <...>`: no copies geometría aquí; cambia los parámetros.
//
//  Render (desde hardware/cad/):
//    xvfb-run -a openscad -o ../../docs/assets/diagramas/cad/patio-fase-2-3d.png \
//      --autocenter --viewall --imgsize=1400,1000 --projection=p \
//      --colorscheme=Tomorrow --camera=0,0,0,42,0,200,0 patio_fase2.scad
// ============================================================================
use <tunel_3x6.scad>
use <rack_charolas.scad>
use <linea_nft.scad>

/* ------------------------------ Patio (supuesto) ------------------------------- */
patio_x  = 10000;   // [mm] (10 m, este–oeste)
patio_y  = 8000;    // [mm] (8 m, sur–norte)
barda_h  = 2200;    // altura de bardas laterales y norte [mm] (supuesto)
barda_e  = 150;
casa_h   = 3000;    // fachada sur de la casa [mm] (supuesto)
acceso_x = [8500, 9500];   // vano del acceso en la barda norte [mm] (supuesto)
puerta_casa_x = [7500, 8400]; // puerta de la casa al patio [mm] (supuesto)

/* ------------------------------ Túnel 5 × 6 ------------------------------------ */
tunel_ancho = 5000;
tunel_largo = 6000;
tunel_n     = 4;                 // 8 columnas
tunel_cx    = 3000;              // eje longitudinal del túnel (x) [mm]
tunel_y0    = 1000;              // cabecera sur del túnel [mm]; la puerta queda al norte (y = 7000)

/* ------------------------------ NFT ------------------------------------------- */
nft_lineas_por_bancada = 4;
nft_sep_lineas         = 350;    // entre ejes de tubo [mm]
nft_y_alto             = 4500;   // extremo ALTO (norte) de las líneas [mm]; el bajo queda en 1500
nft_bancadas_cx        = [1600, 4400];   // centro de cada bancada en x [mm]; pasillo central de 1.55 m

/* ------------------------------ Depósitos ------------------------------------- */
tambo_d  = 580;   tambo_h  = 900;    // tambo HDPE 200 L (dimensiones típicas; medir el que compres)
tambo_pos = [3000, 1300];            // dentro del túnel, entre los retornos de las bancadas
tinaco_d = 1100;  tinaco_h = 1400;   // tinaco 750 L: [POR VERIFICAR: medidas de la ficha Rotoplas Resistec 750 L]
tinaco_pos = [6600, 6800];           // fuera del túnel, junto a la bajante del canalón este
base_tinaco_h = 150;                 // base firme y elevada (03-instalacion §1.2)

/* ------------------------------ Racks ----------------------------------------- */
// [x del respaldo, y inicial, rotación]: 2 racks contra la pared oeste, 1 contra la este
racks = [[1057, 4800, 90], [1057, 5800, 90], [4943, 5700, -90]];

/* ------------------------------ Otros ----------------------------------------- */
gabinetes = [[5300, 1250, 1300], [5300, 1250, 1750], [560, 6700, 1500]];   // A (CA), B (CC), nodo riego
coladera_pos = [9000, 2000];        // supuesta
refri_pos    = [9200, 500];         // refrigerador usado 9–11 pies (zona de cosecha bajo techo, supuesto)
mesa_pos     = [7600, 500];         // mesa de cosecha/empaque

mostrar_etiquetas = true;
rot_etiquetas     = 180;            // 180 = legible con la cámara al norte (rz ≈ 200)
mostrar_titulo    = true;
$fn = 32;

/* ------------------------------ Colores ---------------------------------------- */
col_piso    = [0.80, 0.79, 0.76];
col_barda   = [0.85, 0.84, 0.80];
col_casa    = [0.90, 0.86, 0.76];
col_tambo   = [0.15, 0.25, 0.55];
col_tinaco  = [0.20, 0.20, 0.22];
col_gab     = [0.75, 0.75, 0.78];
col_refri   = [0.92, 0.92, 0.92];
col_mesa    = [0.70, 0.70, 0.72];
col_texto   = [0.12, 0.16, 0.22];
col_acento  = [0.18, 0.49, 0.20];   // #2e7d32
col_pvc_g   = [0.62, 0.62, 0.62];

/* ================================ Auxiliares ================================== */
module etiqueta(txt, pos, size = 260, col = col_texto) {
    if (mostrar_etiquetas) color(col) translate([pos[0], pos[1], 1]) rotate([0, 0, rot_etiquetas])
        linear_extrude(1) text(txt, size = size, font = "DejaVu Sans", halign = "center");
}
module flecha_norte(pos) {
    color(col_acento) translate([pos[0], pos[1], 1]) {
        linear_extrude(2) polygon([[-60, 0], [60, 0], [60, 500], [180, 500], [0, 800], [-180, 500], [-60, 500]]);
        translate([0, -320, 0]) rotate([0, 0, rot_etiquetas]) linear_extrude(2) text("N", size = 260, font = "DejaVu Sans:style=Bold", halign = "center");
    }
}

/* ================================ Patio ======================================= */
// piso
color(col_piso) translate([0, 0, -120]) cube([patio_x, patio_y, 120]);
// casa (fachada sur) con puerta al patio
color(col_casa) difference() {
    translate([0, -300, 0]) cube([patio_x, 300, casa_h]);
    translate([puerta_casa_x[0], -320, -1]) cube([puerta_casa_x[1] - puerta_casa_x[0], 340, 2100]);
}
// coladera (supuesta)
color([0.25, 0.25, 0.25]) translate([coladera_pos[0] - 100, coladera_pos[1] - 100, -2]) cube([200, 200, 2]);

/* ================================ NFT: 2 bancadas de 4 ========================= */
for (cx = nft_bancadas_cx)
    translate([cx, nft_y_alto, 0]) rotate([0, 0, -90])
        bancada_nft(n_lineas = nft_lineas_por_bancada, sep_lineas = nft_sep_lineas);

// tambo 200 L (depósito de solución, tapado y a la sombra dentro del túnel) + bombas 12 V
color(col_tambo) translate([tambo_pos[0], tambo_pos[1], 0]) cylinder(d = tambo_d, h = tambo_h);
color([0.30, 0.30, 0.32]) translate([tambo_pos[0], tambo_pos[1], tambo_h]) cylinder(d = tambo_d + 20, h = 25);   // tapa
color(col_gab) translate([tambo_pos[0] + 380, tambo_pos[1] - 200, 0]) cube([140, 90, 100]);                      // bomba diafragma 12 V principal
color(col_gab) translate([tambo_pos[0] + 380, tambo_pos[1] + 110, 0]) cube([140, 90, 100]);                      // bomba de respaldo
// retorno 2" de cada bancada hacia el tambo (a la altura del retorno común)
zr = 900 - 3000 * 2.5 / 100 - 114 / 2 - 60 - 200;
color(col_pvc_g) {
    translate([nft_bancadas_cx[0] + (3 * nft_sep_lineas) / 2 + 200, nft_y_alto - 3000 + 90, zr]) rotate([0, 90, 0])
        cylinder(d = 60, h = tambo_pos[0] - tambo_d / 2 - (nft_bancadas_cx[0] + (3 * nft_sep_lineas) / 2 + 200));
    translate([tambo_pos[0] + tambo_d / 2, nft_y_alto - 3000 + 90, zr]) rotate([0, 90, 0])
        cylinder(d = 60, h = (nft_bancadas_cx[1] - (3 * nft_sep_lineas) / 2 - 200) - (tambo_pos[0] + tambo_d / 2));
}

/* ================================ Tinaco 750 L ================================ */
color([0.55, 0.55, 0.55]) translate([tinaco_pos[0] - tinaco_d / 2 - 100, tinaco_pos[1] - tinaco_d / 2 - 100, 0])
    cube([tinaco_d + 200, tinaco_d + 200, base_tinaco_h]);                                   // base firme
color(col_tinaco) translate([tinaco_pos[0], tinaco_pos[1], base_tinaco_h]) cylinder(d = tinaco_d, h = tinaco_h);
color([0.35, 0.35, 0.37]) translate([tinaco_pos[0], tinaco_pos[1], base_tinaco_h + tinaco_h]) cylinder(d1 = tinaco_d, d2 = 400, h = 200);
// bajante del canalón este → filtro de hojas → tinaco (tramo horizontal, 3")
color([0.93, 0.93, 0.90]) translate([tunel_cx + tunel_ancho / 2 + 95 + 400, tunel_y0 + tunel_largo + 40, 250]) rotate([0, 90, 0])
    cylinder(d = 75, h = tinaco_pos[0] - tinaco_d / 2 - (tunel_cx + tunel_ancho / 2 + 95 + 400));

/* ================================ Racks ======================================= */
for (r = racks) translate([r[0], r[1], 0]) rotate([0, 0, r[2]]) rack_husky(titulo = false, riego = false);

/* ================================ Gabinetes, cosecha ========================== */
for (g = gabinetes) color(col_gab) translate([g[0] - 45, g[1] - 150, g[2]]) cube([90, 300, 300]);
color(col_refri) translate([refri_pos[0], refri_pos[1], 0]) cube([600, 650, 1500]);
color(col_mesa) translate([mesa_pos[0], mesa_pos[1], 0]) { translate([0, 0, 800]) cube([1200, 600, 40]); for (x = [20, 1140]) for (y = [20, 540]) translate([x, y, 0]) cube([40, 40, 800]); }
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

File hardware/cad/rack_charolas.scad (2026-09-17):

// ============================================================================
//  rack_charolas.scad — Rack Husky 5 niveles 1830 × 914 × 457 mm con charolas 1020 y
//  tubos LED T8 de 120 cm (HomeGreen · Fase 0 y Fase 1).
//  Modelo paramétrico OpenSCAD (probado con OpenSCAD 2021.01). Unidades: mm.
//
//  Ejes: X = ancho del rack (914), Y = fondo (457), Z = altura (1830).
//  Origen en la esquina inferior izquierda TRASERA: el frente del rack mira hacia -Y.
//
//  Fuentes: bom/fase0.csv y bom/fase1.csv (Husky 5 niveles 183 × 91.4 × 45.7 cm,
//  362.9 kg/repisa; entrepaños de MDF que hay que forrar; 8 tubos LED T8 18 W 120 cm =
//  2 por nivel iluminado), docs/referencia/03-instalacion.md §0.2 (nivel superior =
//  germinación/oscuridad, niveles medios = desarrollo, nivel inferior = recién sembradas;
//  separación vertical ≥ 30 cm) y docs/referencia/08-recetas-y-economia-unitaria.md
//  (charola 1020 = 25 × 50 cm).
//
//  Render (desde hardware/cad/):
//    xvfb-run -a openscad -o ../../docs/assets/diagramas/cad/rack-charolas.png \
//      --autocenter --viewall --imgsize=1400,1000 --projection=p \
//      --colorscheme=Tomorrow --camera=0,0,0,72,0,22,0 rack_charolas.scad
// ============================================================================

/* ------------------------------ Rack ------------------------------------------- */
rack_ancho = 914;     // [mm]
rack_fondo = 457;     // [mm]
rack_alto  = 1830;    // [mm]
niveles    = 5;
poste_a    = 38;      // sección del poste (perfil cuadrado equivalente) [mm]
poste_e    = 1.5;
riel_h     = 35;      // altura del bastidor de cada entrepaño [mm]
mdf_esp    = 15;      // entrepaño laminado (MDF) original del Husky [mm]
forro_esp  = 4;       // forro plástico / charola de drenaje sobre el MDF [mm]
z_primer_nivel = 150; // cara superior del entrepaño 1 (abajo) [mm]
z_ultimo_nivel = 1790;// cara superior del entrepaño 5 (arriba) [mm]

/* ------------------------------ Charolas --------------------------------------- */
charola            = [254, 508, 60];  // charola 1020: 10 × 20 in × 6 cm
charola_pared      = 2;
charolas_por_nivel = 3;               // 3 × 254 = 762 ≤ 914; la charola (508) sobresale
                                      // 25 mm por delante y por detrás del fondo de 457
sep_charolas       = 20;              // separación entre charolas [mm]
sustrato_h         = 30;              // ~3 cm de fibra de coco (03-instalacion §0.3)
// Estado de cada nivel, de abajo (1) hacia arriba (5). Opciones:
//   "tapada"     = recién sembrada, con segunda charola invertida y peso encima (2–4 kg)
//   "brote"      = 2–4 días, recién destapada
//   "desarrollo" = 5–8 días
//   "cosecha"    = 8–12 días, lista para cortar
estado_niveles = ["tapada", "brote", "desarrollo", "cosecha", "tapada"];

/* ------------------------------ Iluminación T8 --------------------------------- */
t8_L               = 1200;  // tubo LED T8 120 cm (sobresale 143 mm por lado del rack de 914)
t8_d               = 26;
t8_por_nivel       = 2;
niveles_iluminados = [1, 2, 3, 4];   // el nivel 5 (superior) es de oscuridad: sin tubos → 8 tubos

/* ------------------------------ Riego ------------------------------------------ */
mostrar_riego  = true;   // riser ½" en el poste trasero + lateral con 3 nebulizadores por nivel
riser_d        = 21;     // PVC ½" [mm]
lateral_d      = 10;
nebulizadores_por_nivel = 3;

mostrar_titulo = true;
$fn = 24;

/* ------------------------------ Colores ---------------------------------------- */
col_acero    = [0.16, 0.16, 0.17];
col_mdf      = [0.80, 0.68, 0.48];
col_forro    = [0.08, 0.08, 0.08];
col_charola  = [0.12, 0.12, 0.12];
col_sustrato = [0.36, 0.26, 0.16];
col_brote    = [0.80, 0.85, 0.45];
col_verde    = [0.36, 0.66, 0.30];
col_cosecha  = [0.18, 0.50, 0.22];
col_peso     = [0.55, 0.52, 0.50];
col_t8       = [0.98, 0.98, 0.88];
col_pvc      = [0.93, 0.93, 0.90];
col_texto    = [0.12, 0.16, 0.22];

/* ================================ Funciones ==================================== */
// Cara superior del entrepaño i (1 = abajo … niveles = arriba)
function z_nivel(i, n = niveles, z1 = z_primer_nivel, zn = z_ultimo_nivel) = z1 + (i - 1) * (zn - z1) / (n - 1);
// Claro libre entre la charola de un nivel y el tubo T8 del nivel de arriba
function claro_libre(i) = z_nivel(i + 1) - riel_h - t8_d - 8 - (z_nivel(i) + forro_esp + charola[2]);
// ¿Está el valor v en la lista l?
function en(v, l) = len([for (x = l) if (x == v) x]) > 0;

/* ================================ Piezas ====================================== */
// Charola 1020 hueca (pared 2 mm), origen en su esquina inferior
module charola_1020(c = charola, p = charola_pared) {
    color(col_charola, 0.95) difference() {
        cube(c);
        translate([p, p, p]) cube([c[0] - 2 * p, c[1] - 2 * p, c[2]]);
    }
}

// Charola con su contenido según el estado
module charola_con_cultivo(estado = "desarrollo", c = charola, p = charola_pared) {
    charola_1020(c, p);
    // sustrato
    color(col_sustrato) translate([p, p, p]) cube([c[0] - 2 * p, c[1] - 2 * p, sustrato_h]);
    if (estado == "tapada") {
        // segunda charola invertida encima + dos "pesos" (ladrillo/bolsa de 2–4 kg)
        translate([0, 0, 2 * c[2] + 2]) mirror([0, 0, 1]) charola_1020(c, p);
        color(col_peso) for (y = [c[1] * 0.25, c[1] * 0.75]) translate([c[0] / 2 - 90, y - 50, 2 * c[2] + 2]) cube([180, 100, 55]);
    } else if (estado == "brote") {
        color(col_brote) translate([p, p, p + sustrato_h]) cube([c[0] - 2 * p, c[1] - 2 * p, 15]);
    } else if (estado == "desarrollo") {
        color(col_verde) translate([p, p, p + sustrato_h]) cube([c[0] - 2 * p, c[1] - 2 * p, 45]);
    } else {  // "cosecha"
        color(col_cosecha) translate([p, p, p + sustrato_h]) cube([c[0] - 2 * p, c[1] - 2 * p, 85]);
    }
}

// Entrepaño i: bastidor + MDF + forro
module entrepano(i) {
    z = z_nivel(i);
    color(col_acero) difference() {
        translate([0, 0, z - riel_h]) cube([rack_ancho, rack_fondo, riel_h]);
        translate([poste_a, poste_a, z - riel_h - 1]) cube([rack_ancho - 2 * poste_a, rack_fondo - 2 * poste_a, riel_h + 2]);
    }
    color(col_mdf) translate([poste_a - 5, poste_a - 5, z - mdf_esp]) cube([rack_ancho - 2 * poste_a + 10, rack_fondo - 2 * poste_a + 10, mdf_esp]);
    color(col_forro) translate([4, 4, z]) cube([rack_ancho - 8, rack_fondo - 8, forro_esp]);
}

// Tubo LED T8 a lo largo de X
module tubo_t8(L = t8_L, d = t8_d) {
    color(col_t8) rotate([0, 90, 0]) cylinder(d = d, h = L);
    color([0.2, 0.6, 0.3]) for (x = [0, L - 25]) translate([x, 0, 0]) rotate([0, 90, 0]) cylinder(d = d + 1, h = 25);  // casquillos
}
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

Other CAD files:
hardware/cad/tunel_3x6.scad
hardware/cad/tunel_5x6.scad

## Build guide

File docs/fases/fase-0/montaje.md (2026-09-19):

# Montar el rack y elegir el sitio

**En una línea:** eliges el punto del patio con luz indirecta (100–200 µmol/m²s), 16–24 °C
medidos durante 3 días y agua a menos de 10 m; armas, forras y nivelas el rack Husky y rotulas
qué nivel hace qué — un día de trabajo, y ninguna charola desnivelada (desnivel = agua en una
esquina = moho).

!!! info "Antes de empezar"
    - **Tiempo:** 10 min/día × 3 días de medición + 1 día de montaje (rack 1.5–2 h, estación de siembra 1 h, trazo de la reserva del túnel 30 min) · **Costo:** rack $2,019 Husky o ~$1,300 Adir ([compras](compras.md)) + plástico grueso para forrar entrepaños [POR VERIFICAR: no está en el BOM; sirve un rollo de plástico negro de tlapalería o charolas lisas extra] · **Personas:** 1 (2 para mover el rack armado)
    - **Necesitas:** rack, nivel de burbuja ([torpedo magnético ~$200, Home Depot](https://www.homedepot.com.mx/s/nivel+torpedo)), flexómetro 5 m, calzas (retazos de madera o plástico), plástico o charolas lisas para forrar, masking + marcador indeleble, teléfono con la app **Photone** (gratis, mide µmol/m²s) y una app de trayectoria solar (Sun Surveyor o similar), termómetro con mín/máx, hilo y estacas ([04-herramientas](../../referencia/04-herramientas.md)).
    - **Prerequisitos:** [Comprar el equipo](compras.md) · [Antes de gastar un peso](../../empieza-aqui/antes-de-gastar-un-peso.md) (¿patio propio o condominio?) · [Layout del patio](../../diseno/layout-patio.md) y [Rack y charolas](../../diseno/rack-y-charolas.md) para los porqués del diseño.

## Cómo queda

Planta del patio en Fase 0 a escala 1:50: rack Husky bajo el cobertizo en la pared sur, mesa de siembra 1.2 × 0.6 m, cubeta de remojo y tina de lavado junto a la toma de agua, coladera libre, contacto existente y reserva del túnel 3 × 6 m trazada con hilo

??? note "Leyenda y notas clave del plano"

    --8<-- "assets/diagramas/layout/patio-fase-0.notas.md"

Lectura del plano (supuesto: patio de 10 × 8 m, casa al sur, acceso al norte, coladera en la
esquina noreste, piso de losa; si el tuyo difiere, cambia las constantes de `GEOMETRIA` en
`hardware/cad/layout.py` y regenera):

- **Rack bajo el cobertizo, pegado a la pared sur.** Ahí hay luz indirecta todo el día y el sol
  de mediodía —que a 19° N viene del sur y muy alto— no le pega; tampoco el goteo del alero.
- **Mesa de siembra junto a la toma de agua** (1.9 m en el dibujo; la regla es < 10 m) con la
  cubeta de remojo, la tina de lavado y la cubeta de sustrato usado.
- **Contacto existente cerca del rack.** En Fase 1 ese circuito se vuelve GFCI; en Fase 0 solo
  alimenta un timer si decides poner tubos.
- **Pasillo ≥ 0.9 m frente al rack y coladera libre.** Son las dos reglas que se conservan
  aunque cambie la forma del patio.
- **Reserva del túnel 3 × 6 m trazada desde ahora** (línea punteada): no se construye nada,
  pero no se estorba con nada pesado.

## Pasos

### 1. Elige el sitio (3 días antes de armar nada)

1. **Mide la luz con Photone.** Tres lecturas al día (9, 13 y 17 h) en el punto candidato, con
   el teléfono a la altura del nivel 3 del rack (~1 m). Meta: **100–200 µmol/m²s** de luz
   indirecta. *Criterio de listo:* las tres lecturas de los tres días caen en el rango; si la lectura
   de las 13 h se dispara muy por encima del rango, es sol directo y el punto no sirve.
2. **Descarta sol directo de mediodía y goteo.** Con la app de sol confirma que entre las 11 y
   las 16 h ninguna trayectoria (marzo–septiembre, índice UV 11+) cae sobre el rack; a
   2,240 msnm el UV quema microgreens tiernos. Bajo alero o cobertizo, y sin que la lluvia de
   junio–septiembre (132–176 mm/mes) escurra encima
   ([research/clima-agronomía §3–5](../../research/clima-agronomia.md)).
3. **Registra la temperatura mín/máx 3 días.** Ideal **16–24 °C**; por debajo de 14 °C la
   germinación se vuelve lenta, por encima de 27 °C desordenada. En septiembre–octubre las
   medias de Tacubaya son 17.6–18.4 °C: sin problema. Si tu Fase 0 cae en diciembre–febrero
   (noches de 5–9 °C en el centro, 5–6 °C en el sur), planea tapete térmico o el punto más
   cálido de la casa para la pila de oscuridad ([germinar en invierno](../../guias/germinar-en-invierno.md)).
4. **Confirma los servicios.** Toma de agua a < 10 m; contacto eléctrico a la mano; coladera
   funcionando (échale 10 L y mira que trague); piso plano (nivel de manguera entre las cuatro
   esquinas del rack: diferencia ≤ 1 cm o hay que calzar).
5. **Anota las mediciones** en `bitacora/produccion.csv` (campo `observaciones` de la primera
   fila, o una fila `SITIO-AAMMDD`): T mín/máx por día, µmol por hora. Es el primer dato del
   proyecto y lo vas a comparar contra el túnel en Fase 1.

### 2. Arma el rack

1. **Monta los 5 entrepaños con paso uniforme** (~43 cm entre caras en el Husky de 183 cm;
   la regla es ≥ 30 cm para que quepa charola + brote + mano). Capacidad de placa
   362.9 kg/repisa contra una carga real de ~12 kg por nivel (3 charolas dobles con coco
   saturado a 2.5–4 kg) y ≤ 30 kg en la pila de oscuridad con sus pesos: sobra margen.
   Rack cargado ≈ 60–90 kg + peso propio [POR VERIFICAR: peso del rack en la caja].
2. **Forra cada entrepaño.** El Husky trae entrepaños de MDF laminado: con agua se hinchan.
   Plástico grueso grapado por debajo o una charola lisa como bandeja; nada de dejar el MDF
   desnudo. *Criterio de listo:* derramas 200 mL de agua sobre el entrepaño y no toca madera.
3. **Nivela.** Nivel de burbuja en las dos direcciones sobre cada entrepaño; calza las patas
   con retazos hasta centrar la burbuja. Prueba definitiva: una charola lisa con 1 cm de agua
   en N1 y otra en N5; si el agua se carga a una esquina, sigue calzando. *Criterio de listo:*
   lámina de agua pareja en los dos niveles.
4. **Charola colectora bajo N1 → manguera → coladera.** Lo que escurra del riego por abajo no
   se queda en el piso (charco = mosca fungosa).
5. **Posición final.** Espalda a la pared, frente al pasillo de ≥ 0.9 m. Si en Fase 1 vas a
   poner T8 de 120 cm, deja ≥ 0.3 m libres a cada lado (los tubos vuelan 14.3 cm por lado del
   rack de 91.4 cm).

### 3. Rotula las zonas por nivel

Con masking en el poste, de arriba hacia abajo. La charola **baja un nivel conforme avanza**:
arriba es más cálido (germina rápido), abajo más fresco (frena el estiramiento antes de cortar).

| Nivel | Zona | Qué hay | Días del ciclo | Riego |
|---|---|---|---|---|
| **N5** (arriba, más cálido) | **Oscuridad / blackout** | Charolas recién sembradas, apiladas con peso de 2–4 kg encima, cubierta opaca (tela o plástico negro) | 0 → 2–4 | A mano: atomizar 1–2×/día |
| **N4** | Destape | Luz indirecta; primer verdeo | 3–5 | Solo por abajo (perforada dentro de lisa) |
| **N3** | Desarrollo | Tallo y cotiledón abiertos | 5–8 | Solo por abajo |
| **N2** | Acabado | Color y densidad finales | 8–10 | Solo por abajo |
| **N1** (abajo, más fresco) | Pre-cosecha → cosecha | Se corta la mañana de la entrega | 8–12 | Suspender 12–24 h antes de cortar |

En verano, con más de 27 °C arriba, el SOP de [03 §0.2](../../referencia/03-instalacion.md)
permite lo contrario: recién sembradas al nivel inferior, el más fresco. En septiembre–octubre
no hace falta.

Alzado del rack Husky 183 × 91 × 46 cm: 5 niveles con paso de 43 cm, 3 charolas 1020 por nivel, N5 zona blackout con peso 2–4 kg, N4 destape, N3 desarrollo, N2 acabado, N1 cosecha; charola colectora a coladera; vista lateral y planta de un nivel; tubos T8 y nebulizadores son de Fase 1

??? note "Leyenda, flujo de charolas y tablas del alzado"

    --8<-- "assets/diagramas/layout/rack-alzado.notas.md"

Render 3D del rack con charolas en los cuatro estados del SOP (tapada, brote, desarrollo, cosecha), tubos T8 por nivel y riser de riego

**Capacidad (geometría del entrepaño de 91.4 × 45.7 cm):** caben 3 charolas 1020 atravesadas
por nivel (3 × 25.4 = 76.2 cm; vuelan 5.1 cm al frente). En luz (N1–N4): 12 posiciones; en
N5: 3 pilas de 2–3 charolas. Total ≈ 18–21 charolas en proceso por rack
[POR VERIFICAR con el rack armado]. **En Fase 0 el límite real no es el rack sino las 10
charolas dobles del BOM** (~10 en proceso ≈ 6 cosechadas por semana); si en la semana 3 ya hay
pedidos, compra 10 perforadas y 10 lisas más ([compras §"cuando pase G0"](compras.md)).

### 4. Arma la estación de siembra y lavado

- **Mesa de 1.2 × 0.6 m junto a la toma**, superficie lavable (plástico o acero; no madera
  desnuda: [NOM-251 aplicada](../../research/inocuidad-operativa.md)). Encima: báscula de
  precisión, báscula de cocina, tijera, termómetro, masking y marcador.
- **Cubeta de 19 L marcada en litros** solo para remojo (se lava y desinfecta entre lotes);
  **tina de lavado** para charolas; **cubeta de sustrato usado** que sale del área de producción
  el mismo día de la cosecha (composta o recolección de orgánicos; una charola con fusarium va a
  la basura en bolsa cerrada, nunca a la composta).
- **Dos atomizadores, uno etiquetado "H2O2 3 %"** que nunca toca agua de riego.
- Corte y empaque en la misma mesa pero **nunca sobre tierra ni con las charolas de cultivo
  encima**: la separación puede ser una cortina o simplemente el orden (primero cortar y
  empacar, después sembrar).

### 5. Traza la reserva del túnel (30 min, gratis)

No es de esta fase, pero cuesta cero y evita que el patio se llene de cosas donde va la
estructura de Fase 1:

1. Marca un rectángulo de **3 × 6 m** a ≥ 0.6 m de las bardas laterales y ≥ 0.8 m de la barda
   norte, con hilo y estacas; escuadra 3-4-5 y diagonales iguales ± 1 cm.
2. Revisa el piso dentro del rectángulo: grietas, bordes de losa a menos de 15 cm de donde irían
   las placas (ahí no se ancla), pendiente hacia la coladera.
3. Foto con fecha; nada pesado encima durante la Fase 0.
4. Si el patio es de condominio, el Art. 21/23 de la Ley de Propiedad en Condominio pide
   asamblea antes de perforar ([07 §9](../../referencia/07-puntos-ciegos-y-riesgos.md)):
   empieza a preguntar ahora, no en Fase 1.

!!! warning "Errores típicos"
    - **Rack "donde cabe" en vez de donde hay luz indirecta.** Un rack en el sol de la tarde
      cocina las charolas de N5 (>27 °C = germinación desordenada) y uno en un rincón oscuro da
      tallos largos y pálidos. Los 3 días de medición valen más que el rack.
    - **Charolas desniveladas.** Con riego por abajo, 5 mm de desnivel juntan el agua en una
      esquina y el moho aparece en 48 h. Calza hasta que la lámina de agua sea pareja.
    - **MDF sin forrar.** Se hincha en dos semanas y ya no nivela nunca.
    - **Tapar la coladera con la charola colectora o la cubeta.** Tormenta de septiembre = patio
      inundado y charolas de N1 flotando.

## Al terminar

- [ ] 9 lecturas de Photone (3 días × 3 horas) dentro de 100–200 µmol/m²s y sin sol directo de 11–16 h
- [ ] 3 días de T mín/máx dentro de 16–24 °C (o plan de tapete térmico anotado)
- [ ] Rack nivelado en sus 5 entrepaños (prueba de la lámina de agua en N1 y N5), entrepaños forrados
- [ ] Charola colectora conectada a la coladera; coladera traga 10 L
- [ ] Niveles rotulados N5→N1; masking y marcador en la mesa
- [ ] Estación de siembra armada; atomizador de H2O2 etiquetado; cubeta de remojo marcada en litros
- [ ] Reserva del túnel trazada y fotografiada
- **Registrar** en `bitacora/produccion.csv`: fila `SITIO-AAMMDD` con T mín/máx de los 3 días y
  las lecturas de luz en `observaciones`; foto del rack nivelado en `bitacora/fotos/`.
- **Siguiente paso:** [Sembrar las primeras 6 semanas](siembra.md).

## Fuentes

- [03-instalación §0.1–0.2](../../referencia/03-instalacion.md) (selección del sitio, montaje del rack, zonas)
- [02-restricciones §1](../../referencia/02-restricciones-y-requisitos.md) y [research/clima-agronomía](../../research/clima-agronomia.md) (UV, temperaturas mensuales, lluvia)
- [07-puntos ciegos §9 y §12](../../referencia/07-puntos-ciegos-y-riesgos.md) (condominio, residuos)
- [research/inocuidad-operativa §4](../../research/inocuidad-operativa.md) (NOM-251 en un cuarto de cosecha casero)
- Diagramas: `docs/assets/diagramas/layout/patio-fase-0.svg`, `rack-alzado.svg`; modelo [`hardware/cad/rack_charolas.scad`](https://github.com/AndresIslas99/HomeGreen/blob/main/hardware/cad/rack_charolas.scad)
- Guía escrita del rack de producción de On The Grow: [Professional Microgreens Grow Rack Setup](https://onthegrow.net/blogs/microgreens/professional-microgreens-grow-rack-setup-step-by-step-build-guide) (inglés)

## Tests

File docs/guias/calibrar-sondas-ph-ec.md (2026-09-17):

# Calibrar las sondas de pH y EC

**En una línea:** cada quince días sacas las sondas del retorno, calibras el pH a dos puntos con buffers 4.01 y 6.86 y la EC contra el patrón de 1.413 mS/cm, contrastas con el medidor de mano (≤ 0.1 de diferencia) y anotas voltajes y pendiente — porque una sonda barata no falla callando, falla **mintiendo**, y el lazo dosifica sobre lo que la sonda dice.

!!! info "Antes de empezar"
    - **Tiempo:** ~30 min (estimado) **cada 15 días**, como evento de `calendar.huerto` con alarma; +30 min la primera vez (offset de la placa y medidor de mano) · **Costo:** buffer pH 4.01 120 mL **$40** ×2/año ([Insumos Cerveceros](https://insumoscerveceros.mx/inicio/1305-solucion-para-calibracion-de-ph-buffer-401-120-ml.html)), sobres 6.86 ~$15 aprox. ×10 ([Mercado Libre](https://listado.mercadolibre.com.mx/solucion-buffer-para-calibrar-ph)), patrón EC 1.413 mS/cm Hanna HI7031L 500 mL **$459.36** ([Hanna México](https://hannainst.com.mx/soluci%C3%B3n-de-calibraci%C3%B3n-de-ce-1-413-%C2%B5s-3-cm-valor-hi7031l), caduca 5 años cerrada) → ~$650/año; + electrodo de pH de repuesto anual ~$400–600 → **~$1,050/año** ([06 resumen operativo](../referencia/06-validacion-y-lazos-agenticos.md)) · **Personas:** 1
    - **Necesitas:** los tres patrones, agua destilada, 3 vasos limpios etiquetados (4.01 / 6.86 / EC), papel absorbente, medidor pH + TDS/EC de mano (~$450 aprox., [ML](https://listado.mercadolibre.com.mx/medidor-ph-tds-ec)) como **árbitro**, acceso al panel del nodo NFT en Home Assistant y al YAML de ESPHome, la bitácora
    - **Prerequisitos:** nodo v2 flasheado ([Flashear ESPHome](flashear-esphome.md)) y sondas instaladas en el retorno ([Dosificación v2 §B](../fases/fase-2/dosificacion-v2.md)); tabla de pines y entidades en [Firmware ESPHome](../software/firmware.md) y [Datos §2](../diseno/datos.md)

## Los números del firmware que usa esta guía

Esquema del nodo NFT v2: placa pH por BNC en GPIO34, TDS SEN0244 en GPIO35, ambos con filtro RC 1 kΩ / 100 nF, DS18B20 en GPIO4, peristálticas por MOSFET

| Qué | Valor | Dónde está definido |
|---|---|---|
| Entrada de pH (AT-1) | **GPIO34** (ADC1_6), `attenuation: 12db`, filtro RC 1 kΩ / 100 nF; salida Po de la placa PH-4502C **≤ 3.1 V** en todo el rango | [Eléctrico · tabla de pines](../diseno/electrico.md), [Firmware](../software/firmware.md) |
| Entrada de EC (AT-2) | **GPIO35** (ADC1_7), SEN0244 AOUT vía RC; se calibra **en mS/cm** directo, no en ppm | ídem |
| Temperatura de solución (TT-2) | DS18B20 en GPIO4, `sensor.temperatura_solucion` | ídem |
| Entidades en HA | `sensor.ph_nft`, `sensor.ec_nft`; voltaje crudo de cada sonda [POR VERIFICAR: nombre exacto de las entidades de voltaje en firmware.md; esta guía las llama `pH NFT voltaje` y `EC NFT voltaje`] | [Datos §2](../diseno/datos.md) |
| Patrones | pH **4.01** y **6.86** (el 6.86 es el estándar de las sondas DFRobot); EC **1.413 mS/cm** a 25 °C (a otra temperatura, tabla de la etiqueta) | [research/hidroponia-nft §g](../research/hidroponia-nft.md) |
| Tolerancia de aceptación | sonda fija vs medidor de mano **≤ 0.1 pH** y **≤ 0.1 mS/cm** | [Dosificación v2 §A](../fases/fase-2/dosificacion-v2.md) |
| Bandas de operación | pH 5.8–6.2 · EC 1.2–1.8 mS/cm | [06 L0](../referencia/06-validacion-y-lazos-agenticos.md) |
| Watchdog "sonda no confiable" | sin cambio en 24 h con dosis hechas, o salto > 1.5 unidades en 5 min → dosificación suspendida; **rearme manual** tras calibrar | [06 watchdogs](../referencia/06-validacion-y-lazos-agenticos.md), [Control · Lazo 2](../diseno/control.md) |
| Vida del electrodo de pH | cambio **anual**; caduca a los 12–18 meses aunque no se use (no lo compres antes de tiempo) | [research/electronica-automatizacion §3](../research/electronica-automatizacion.md) |

El ESP32 lee un voltaje; la calibración es la recta que convierte ese voltaje en pH (o mS/cm). Dos puntos definen la recta: por eso son dos buffers.

```mermaid
flowchart LR
    S[Suspender dosificación<br/>en HA] --> M[Calibrar el medidor<br/>de mano con los mismos buffers]
    M --> P[pH: 6.86 → 4.01<br/>anotar V y T]
    P --> C[Calcular m y b<br/>cargar al firmware]
    C --> V{¿6.86 y 4.01 leen ± 0.1<br/>y retorno vs mano ≤ 0.1?}
    V -->|Sí| E[EC: aire → 0<br/>patrón → 1.413]
    V -->|No| R[Repetir con buffer nuevo;<br/>si falla otra vez: electrodo]
    E --> F{¿EC vs mano ≤ 0.1?}
    F -->|Sí| A[Sondas al retorno<br/>rearmar lazo · bitácora]
    F -->|No| R2[Limpiar sonda TDS, repetir;<br/>revisar RC y GND]
    style V fill:#fff7ed,stroke:#b45309
    style A fill:#f0fdf4,stroke:#2e7d32
```

## Pasos

### A. Preparar (5 min)

1. **Suspende la dosificación automática en HA** antes de tocar nada [POR VERIFICAR: nombre del interruptor de mantenimiento en [Home Assistant](../software/home-assistant.md)]. Si no lo haces, sacar la sonda del agua produce un salto > 1.5 y el watchdog la marca "no confiable" de todos modos; mejor que sea a propósito. La bomba de recirculación **sigue**: las raíces no esperan.
2. **Sirve los patrones en los vasos etiquetados**; nunca metas la sonda en el frasco. El sobre de 6.86 se disuelve en agua destilada en el volumen que indica el sobre; el 4.01 y el 1.413 se sirven tal cual. Anota la temperatura de los vasos (deben estar a la del ambiente, cerca de 25 °C; si no, usa la tabla de la etiqueta).
3. **Calibra primero el medidor de mano** con los mismos buffers, según su manual. Es el árbitro: si el árbitro está descalibrado, todo lo que sigue es ruido.

### B. pH a dos puntos (10 min)

4. **Saca el electrodo del retorno**, enjuágalo con agua destilada y **seca por contacto** con papel (nunca frotes el bulbo: se carga estáticamente y tarda minutos en estabilizar).
5. **Buffer 6.86:** sumerge, agita suave 5 s y espera a que el voltaje crudo deje de moverse (típicamente 1–2 min). Anota **V₆.₈₆** y la temperatura.
6. **Enjuaga y seca. Buffer 4.01:** igual. Anota **V₄.₀₁**.
7. **Calcula la recta** (pH = m·V + b):

    ```text
    m = (6.86 − 4.01) / (V₆.₈₆ − V₄.₀₁)        # pendiente, pH por volt (negativa en la PH-4502C)
    b = 6.86 − m · V₆.₈₆                        # offset
    ΔV = V₄.₀₁ − V₆.₈₆                          # "salud" del electrodo: anótala SIEMPRE
    ```

    La primera vez, con el electrodo nuevo, **ΔV es tu referencia**: las calibraciones siguientes se comparan contra ella (ver "cuándo cambiar el electrodo").

8. **Carga la calibración al firmware.** Tres formas; la que usa tu nodo está en [Firmware](../software/firmware.md) [POR VERIFICAR: cuál implementa `nodo-nft-v2.yaml`]:

    === "Opción A · `calibrate_linear` (reflasheo OTA)"

        ```yaml
        # firmware/esphome/nodo-nft-v2.yaml — fragmento ilustrativo; sustituye los V por los tuyos
        sensor:
          - platform: adc
            pin: GPIO34
            attenuation: 12db
            name: "pH NFT"
            id: ph_nft
            update_interval: 5s
            filters:
              - median: { window_size: 15, send_every: 5 }
              - calibrate_linear:
                  - V_6_86 -> 6.86    # p. ej. 2.52 -> 6.86
                  - V_4_01 -> 4.01    # p. ej. 3.05 -> 4.01
        ```

        Cambia los dos pares, guarda y envía por OTA. Sencillo, pero cada calibración es un commit y un reflasheo.

    === "Opción B · offset y pendiente como `number` en HA (sin reflashear)"

        El firmware expone `number.ph_pendiente` y `number.ph_offset` (o equivalentes) y aplica `pH = m·V + b` en una lambda; tú escribes m y b desde el panel de HA y quedan guardados en el ESP32 (`restore_value: true`). Es la forma que no depende de tener la laptop en el patio [POR VERIFICAR: nombres de las entidades en firmware.md].

    === "Opción C · componente r0bb10 (sonda DFRobot, etapa 2)"

        Cuando el NFT venda y pases al kit DFRobot Gravity ($1,250 aprox., [Geek Factory](https://www.geekfactory.mx/producto/kit-sensor-de-ph-para-arduino-gravity-dfrobot/)), el componente externo [ESPHome-DFRobot-pH-Meter](https://github.com/r0bb10/ESPHome-DFRobot-pH-Meter) hace la calibración de 2/3 puntos con **botones en HA**, compensa temperatura y guarda en EEPROM; se instala con 6 líneas de `external_components` ([research/tutoriales-videos §d](../research/tutoriales-videos.md)). Plan B minimalista con `calibrate_linear` puro: [hilo de la comunidad de HA](https://community.home-assistant.io/t/implementing-analog-ph-sensor-of-dfrobot/714202).

9. **Verifica la recta:** con la calibración cargada, vuelve a meter el electrodo en 6.86 y luego en 4.01 (enjuagando entre ambos): `sensor.ph_nft` debe leer cada buffer **± 0.1**. Luego, sonda en el retorno y medidor de mano en la misma agua: **diferencia ≤ 0.1**.
   *Criterio de listo:* los tres números dentro de tolerancia. Si no: buffer nuevo y repetir; si vuelve a fallar, ve a "cuándo cambiar el electrodo".

!!! tip "Primera vez: el offset de la placa PH-4502C"
    La placa trae un potenciómetro de offset. Con el electrodo en el buffer 4.01 (el punto de voltaje más alto en esta placa), ajusta el potenciómetro hasta que Po quede **≤ 3.1 V**: es el rango útil del ADC con `attenuation: 12db` ([Eléctrico](../diseno/electrico.md)). Si Po se sale del rango, el ESP32 lee saturado y "calibra" sobre una pared. No vuelvas a tocar el potenciómetro después: solo cambia m y b.

### C. EC contra patrón (10 min)

10. **Enjuaga la sonda TDS** con destilada y sécala. **En el aire** debe leer **0**: anota el voltaje en aire (V_aire). Si en aire lee distinto de 0, hay ruido en el ADC (revisa el RC y la tierra común) o la sonda está sucia.
11. **Patrón 1.413 mS/cm:** sumerge solo la punta hasta la marca, espera a que estabilice, anota **V₁.₄₁₃** y la temperatura. Carga la recta (V_aire → 0.0, V₁.₄₁₃ → 1.413) con la misma opción que el pH. El patrón vale 1.413 **a 25 °C**; si tu vaso está a otra temperatura, usa el valor de la tabla de la etiqueta del frasco. El firmware compensa la lectura de operación con TT-2 [POR VERIFICAR: coeficiente y fórmula en firmware.md; TDS ≈ EC × 0.5–0.7 si el nodo reporta ppm en algún punto].
12. **Verifica:** `sensor.ec_nft` en el patrón = 1.413 ± 0.1; en el retorno, sonda vs medidor de mano **≤ 0.1 mS/cm**.

### D. Cerrar (5 min)

13. **Enjuaga las dos sondas** y regrésalas al retorno, en la misma posición (boca del retorno dentro del tambo, nunca junto a las peristálticas), con los cables por la prensaestopa y el conector hacia arriba.
14. **Espera lecturas estables** (mediana de 30 s en HA) y **rearma la dosificación** (rearme manual, [Control · Lazo 2](../diseno/control.md)). Vigila la primera hora: ninguna dosis fuera del tiempo muerto de 10–15 min.
15. **Tira los buffers usados** (no regresan al frasco), tapa bien los frascos, anota la fecha de apertura, y programa el siguiente evento en `calendar.huerto` a 15 días.

## Cómo saber que una sonda miente

Las sondas baratas fallan **mintiendo**, no callando: dan un número plausible que ya no tiene relación con el agua. Señales, de la más automática a la más manual:

| Señal | Qué la detecta | Qué hacer |
|---|---|---|
| pH o EC **no cambian en 24 h** aunque hubo dosis | Watchdog (HA) → "no confiable", dosificación suspendida, alarma | Calibrar; si no pasa la verificación, electrodo |
| **Salto > 1.5 unidades en 5 min** | Watchdog | Casi siempre sonda fuera del agua, cable o conector; revisar, calibrar, rearmar |
| **mL dosificados/día > 2× el promedio de 7 días** | Watchdog de deriva | Sonda que lee bajo (pH) o baja (EC) y el lazo persigue un fantasma; contrastar con el medidor de mano **hoy**, no en la quincena |
| Sonda fija vs medidor de mano **> 0.1** en el retorno | Tú, cada quincena (o cuando algo se vea raro) | Calibrar; si tras calibrar sigue > 0.1, electrodo |
| Lectura que **tarda cada vez más en estabilizar** en el buffer, o que sigue derivando dentro del buffer | Tú, al calibrar | Electrodo envejecido; planear el cambio |
| **ΔV cayó** claramente respecto a la primera calibración (electrodo nuevo) | Tú, comparando la bitácora | Electrodo agotado [POR VERIFICAR: umbral en la ficha del E201/DFRobot; práctica de laboratorio: rechazar pendientes muy por debajo de la teórica] |
| pH salta cuando la sonda TDS está energizada, o viceversa | Tú, en el dry-run | Interferencia entre dos sondas analógicas en la misma agua [POR VERIFICAR en el dry-run de dosificación: separar físicamente, alternar lecturas o aislar una de las dos] |
| Plantas que "no responden" a una solución en banda | Rendimiento (L2) | La sonda o el agua base mienten: V7 al agua y calibración fuera de calendario |

**Cuándo cambiar el electrodo de pH** (el consumible caro):

- **Cada año, siempre**, aunque "se vea bien" ([00-plan-maestro](../referencia/00-plan-maestro.md)): presupuestado en los ~$1,050/año.
- Antes, si tras dos calibraciones con buffer nuevo no pasa el ≤ 0.1, si tarda muchos minutos en estabilizar, o si ΔV cayó frente al día 1.
- **No compres el repuesto por adelantado:** el electrodo caduca a los 12–18 meses **aunque no se use**. Compra al mes 10–11 del que está instalado.
- La sonda TDS no tiene bulbo de vidrio: se limpia y dura; si en aire ya no lee 0 después de limpiarla, se cambia (~$450 aprox., [UNIT](https://uelectronics.com/producto/sensor-tds-meter-v1-0-analogico-sen0244/)).

!!! warning "Error típico: calibrar 'cuando se vea raro'"
    La deriva es lenta e invisible; para cuando "se ve raro", el lazo llevó una semana dosificando de más. Quincenal en el calendario con alarma, y la calibración el mismo día que el cambio de solución: la sonda decide la dosis del tanque nuevo.

!!! warning "Error típico: frotar el bulbo, o guardarlo seco"
    Secar el bulbo frotando lo carga y da lecturas que tardan minutos en asentarse; guardarlo seco o en agua destilada lo arruina. Entre usos, siempre húmedo (en el retorno o con su capuchón con solución de almacenamiento). Aquí el electrodo vive en el retorno: el riesgo es la quincena en que lo sacas y lo dejas en la mesa.

!!! warning "Error típico: rearmar sin verificar"
    Volver a activar la dosificación después de una "sonda no confiable" sin calibrar y contrastar es apostar el cultivo a un número aleatorio ([Control · errores típicos](../diseno/control.md)).

## Al terminar

- [ ] Medidor de mano calibrado con los mismos buffers
- [ ] pH: V₆.₈₆, V₄.₀₁, m, b y ΔV anotados; 6.86 y 4.01 leen ± 0.1 con la recta cargada; retorno vs mano ≤ 0.1
- [ ] EC: V_aire = 0, V₁.₄₁₃ anotado con temperatura; patrón lee 1.413 ± 0.1; retorno vs mano ≤ 0.1
- [ ] Sondas de vuelta en la boca del retorno; dosificación rearmada; primera hora sin dosis fuera de tiempo muerto
- [ ] Siguiente calibración en `calendar.huerto` (+15 días); buffers usados desechados
- Registrar en `bitacora/nft.csv`: `evento=calibracion`, `temp_solucion_C`, y en `observaciones`: `pH V6.86=… V4.01=… m=… b=… dV=… mano=… | EC Vaire=… V1413=… T=… mano=… | electrodo instalado AAAA-MM-DD` (así el ΔV de hoy se compara con el del día 1)
- Siguiente paso: [Cambiar la solución del NFT](cambiar-solucion-nft.md) (el mismo día, si toca) o [Preparar la solución](preparar-solucion-nutritiva.md)

## Fuentes

- [referencia/06-validacion](../referencia/06-validacion-y-lazos-agenticos.md) — calibración quincenal con 4.0/6.86 y 1.413, watchdog de sonda no confiable, deriva de dosificación, presupuesto ~$1,050/año
- [referencia/03-instalacion §2.2](../referencia/03-instalacion.md) — calibración quincenal, cambio de sonda anual, sondas en el retorno
- [research/hidroponia-nft §g](../research/hidroponia-nft.md) — buffers 4.01 (Insumos Cerveceros), sobres 6.86, patrón Hanna HI7031L, presupuesto anual
- [research/electronica-automatizacion §3](../research/electronica-automatizacion.md) — PH-4502C en dos etapas, SEN0244 en mS/cm, caducidad del electrodo, medidor de mano como árbitro (`bom/fase2.csv`)
- [research/tutoriales-videos §d](../research/tutoriales-videos.md) — componente r0bb10, hilo de calibrate_linear
- [diseno/electrico](../diseno/electrico.md) (GPIO34/35, 12db, RC, Po ≤ 3.1 V) · [diseno/control](../diseno/control.md) (Lazo 2, rearme manual) · [diseno/datos §2](../diseno/datos.md) (entidades) · [fases/fase-2/dosificacion-v2](../fases/fase-2/dosificacion-v2.md) (tolerancia ≤ 0.1, rutina)

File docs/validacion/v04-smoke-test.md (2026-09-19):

# V4 · Smoke test comercial (vender antes de construir)

**En una línea:** la Fase 0 completa, formalizada como método: 15 restaurantes mapeados, visitas con muestra física, y cada semana las cuatro cifras del embudo —visitados → probaron → pidieron una vez → recurrentes— para saber, antes de gastar $41,634 en el túnel, si alguien paga por SPEI tres semanas seguidas.

!!! info "Antes de empezar"
    - **Cuándo:** Fase 0, semanas 3–6 (las visitas empiezan cuando hay producto cortado esa mañana); se registra **cada semana** · **Tiempo:** 2 mañanas por semana de visitas + 2 entregas; cerrar un cliente cuesta ~8–10 h y ~$650 de bolsillo ([07 §7](../referencia/07-puntos-ciegos-y-riesgos.md)) · **Costo:** muestras (1 charola de girasol = 3–5 muestras de 100 g ≈ $9 de insumo; clamshell $3.50) + transporte · **Personas:** 1
    - **Necesitas:** producto de la semana 2 en adelante, clamshells y etiquetas con lote, hielera con gel packs, hoja de precios de una página, WhatsApp Business, CLABE de negocio, talonario de remisiones; `bitacora/prospectos.csv`, `bitacora/embudo.csv`, `bitacora/ventas.csv`
    - **Guías relacionadas:** [Fase 0 · Vender a chefs](../fases/fase-0/ventas.md) (el paso a paso completo) · [Visitar a un chef](../guias/visitar-a-un-chef.md) · [Hoja de precios](../guias/hoja-de-precios.md) · [Cobrar y suspender](../guias/cobrar-y-suspender.md) · **Desbloquea:** [G0→1 (a)](gates.md)

## Propósito

El riesgo número uno del proyecto es **no vender**, y la Fase 0 existe para acotarlo a ~$6k ([00 · Riesgos](../referencia/00-plan-maestro.md)). El smoke test convierte "creo que los chefs van a querer" en cuatro números semanales. La conversión visitado → recurrente esperable es **10–20 %**: de 15 visitas reales salen 2–3 clientes. Si tras 15 visitas hay **0 recurrentes**, el problema es producto, precio o zona, y se pivota **antes** de la Fase 1 ([06 §V4](../referencia/06-validacion-y-lazos-agenticos.md)).

```mermaid
flowchart LR
    V["Visitados<br/>15 con muestra física"] --> P["Probaron<br/>el chef la comió y opinó"]
    P --> U["Pidieron una vez<br/>entrega cobrada por SPEI"]
    U --> R["Recurrentes<br/>3 compras semanales seguidas"]
    R --> G{{"G0→1 (a): ≥ 2 recurrentes"}}
    V -. "10–20 % esperable" .-> R
    style R fill:#f0fdf4,stroke:#2e7d32
    style G fill:#fff7ed,stroke:#b45309
```

## Definiciones (para que las cuatro cifras no se inflen)

| Cifra | Cuenta si… | No cuenta |
|---|---|---|
| **Visitados** | Entraste con muestra física y hoja de precios y hablaste con el chef, sous chef o administrador (o dejaste muestra + hoja + WhatsApp y confirmaron que la recibió) | Mensajes de WhatsApp sin visita; visitas sin muestra |
| **Probaron** | El chef comió la muestra y dio una opinión (aunque sea "no") | Muestra dejada sin respuesta |
| **Pidieron una vez** | Una entrega con remisión firmada **y SPEI recibido** ese día | Muestra gratis, pedido "para la otra semana", entrega no cobrada |
| **Recurrentes** | **3 semanas ISO consecutivas** con compra cobrada; una semana sin pedido reinicia la racha | El que "seguro pide la próxima" |

El cliente es el **restaurante**, no el chef ([07 §7](../referencia/07-puntos-ciegos-y-riesgos.md)); acumula el acumulado de visitados desde la S3.

## Procedimiento

1. **Mapea 15 restaurantes** en radio de 5 km (cocina de autor, brunch, pokés, coctelería, dark kitchens; excluye < 6 meses operando) y guárdalos en `bitacora/prospectos.csv`. Ningún cliente futuro debe pesar > 25–30 % de tus ventas: la meta son 4–5 medianos, no 1 grande. *Criterio de listo:* 15 filas con zona, tipo, contacto y mejor horario.
2. **Prepara la muestra la mañana de la visita**: clamshell ~100 g (girasol + una fina), etiqueta con `siembra_id`, hielera con gel packs (< 10 °C 4–6 h), una charola viva de exhibición. *Criterio de listo:* muestra cortada hoy, etiquetada, fría.
3. **Visita sin cita, martes a jueves de 10 a 12 h**, con el guion de 90 s de [Vender a chefs §4](../fases/fase-0/ventas.md): quién eres, abre la muestra y cállate, oferta gancho (entrega semanal fija, charola viva, sin mínimo el primer mes, sin crédito), una pregunta ("¿qué usan hoy y cuánto les cuesta?"), cierre con fecha y WhatsApp **del administrador**. *Criterio de listo:* fila de `prospectos.csv` actualizada el mismo día.
4. **A las 48–72 h** manda la foto de la charola del día y una sola pregunta: "¿algo que cambiarías del producto?" *Criterio de listo:* respuesta o silencio anotado (alimenta el KPI de feedback).
5. **Entrega y cobra**: remisión firmada en cada entrega; **SPEI contra entrega, cero excepciones** en Fase 0 (estás validando que *pagan*, no que *quieren*). Cada entrega es una fila en `bitacora/ventas.csv`. *Criterio de listo:* comprobante del SPEI en el teléfono el mismo día.
6. **Domingo: registra el embudo** en `bitacora/embudo.csv` con las cuatro cifras acumuladas de la semana, más muestras regaladas y horas de venta (insumo del CAC). *Criterio de listo:* una fila por semana, S3 a S6, sin huecos.
7. **Aplica las reglas de lectura** escritas de antemano ([06 §L2](../referencia/06-validacion-y-lazos-agenticos.md)): cliente sin pedir 2 semanas → visita presencial; 2 quejas del mismo tipo → cambia el producto esa semana; sell-through < 75 % dos semanas → no siembres más volumen. *Criterio de listo:* cada regla disparada tiene una acción con fecha.
8. **Fin de S6:** cuenta los recurrentes y pasa al [gate G0→1](../fases/fase-0/gate.md). *Criterio de listo:* `recurrentes` de la última fila coincide con la tabla cliente × semana de `ventas.csv`.

## Criterio de aceptación

!!! example "Aceptar el smoke test si"
    - `bitacora/embudo.csv` tiene **las cuatro cifras de cada semana** (S3–S6), sin reconstruir de memoria.
    - Se hicieron **≥ 15 visitas reales** con muestra física (≥ 12 con el chef o sous chef presente).
    - Hay **≥ 2 recurrentes** (3 compras semanales consecutivas, cobradas por SPEI) al cierre de la S6 — es la métrica (a) de [G0→1](gates.md).
    - La conversión visitado → recurrente cae en el rango esperable de **10–20 %** o lo supera.

    Con 15 visitas y **0 recurrentes** el método reprueba: se pivota producto, precio o zona antes de invertir en Fase 1; con 1 recurrente se itera una sola vez, 2 semanas.

## Plantilla de registro

`bitacora/embudo.csv` (una fila por semana, el domingo):

```csv
semana,visitados_acum,probaron_acum,pidieron_una_vez_acum,recurrentes,conversion_pct,muestras_regaladas_sem,horas_venta_sem,observaciones
2026-W41,8,6,1,0,0,7,6.5,"ronda 1 Roma-Condesa; 2 chefs ausentes: volver jueves"
2026-W42,15,12,4,0,0,9,7.0,"ronda 2 Coyoacan; primer pedido cobrado martes (RestA)"
2026-W43,15,12,5,1,7,3,3.5,"RestA 3a semana seguida; RestB pidio 2 veces"
2026-W44,15,13,5,2,13,2,3.0,"RestB completa 3 semanas; RestC sin pedir 2 semanas -> visita presencial"
```

- `conversion_pct` = `recurrentes ÷ visitados_acum × 100`.
- `muestras_regaladas_sem` y `horas_venta_sem` alimentan el CAC de [KPIs](kpis.md) (umbral rojo: > 3 visitas y 3 muestras por cliente cerrado).
- `bitacora/prospectos.csv` (una fila por restaurante): `restaurante,zona,tipo,chef,administrador,whatsapp,mejor_horario,fecha_visita,probo,pidio,semanas_seguidas,notas`.
- `bitacora/ventas.csv` (una fila por entrega): `fecha,cliente,producto,cantidad,precio_unit_mxn,entregado_a_tiempo,feedback` — es lo que lee `tools/gate_audit.py`.

## Si falla

| Resultado en S6 | Lectura | Qué hacer |
|---|---|---|
| ≥ 2 recurrentes | Pasa (a) | [Gate G0→1](../fases/fase-0/gate.md): revisa (b) margen ≥ 55 % |
| 1 recurrente, ≥ 4 pidieron una vez | Producto gusta, recurrencia no cuaja: día de entrega, formato o precio | Iterar **una vez, 2 semanas**: charola viva en vez de cortado; entrega el día que ellos piden; acuerdo de 1 página con el administrador |
| 0 recurrentes, ≥ 12 probaron y opinaron | Precio o formato | Cambiar lo que dijeron en el feedback (ese es el dato); quitar promos que no convierten; probar rábano/arúgula si solo llevabas girasol |
| 0 recurrentes, < 8 probaron | Zona o guion: no llegas al chef | Cambiar zona (Roma–Condesa ↔ Coyoacán–San Ángel), horario, o dejar muestra con el administrador y volver |
| 0 recurrentes tras 15 visitas reales | Producto/precio/zona | **Pivotar antes de la Fase 1**: post-mortem de una página (embudo, feedback textual, precios ofrecidos vs aceptados) y decisión de abortar con pérdida acotada ~$6k |
| Visitados < 15 en S6 | El método no se corrió | No hay gate que evaluar: completar las 15 antes de decidir |

!!! warning "Errores típicos"
    - Vender a $60–90 "para entrar": solo el girasol de CEDA sobrevive ese precio; la promo es del primer mes y solo en girasol.
    - Dar crédito "porque es el primer cliente": un cliente que quiere pero no paga no cuenta.
    - Formalizar con el chef y no con el administrador o dueño.
    - Contar como recurrente al que "seguro pide la próxima semana".
    - Entregar cortado sin frío: muere en horas y la muestra vende lo contrario.

## Al terminar

- [ ] 15 restaurantes visitados con muestra; `prospectos.csv` completo
- [ ] `embudo.csv` con las 4 cifras de S3, S4, S5 y S6
- [ ] `ventas.csv` con cada entrega, remisiones firmadas archivadas, SPEI conciliados
- [ ] ≥ 2 recurrentes (o la decisión de iterar/abortar escrita)
- [ ] Feedback de ≥ 50 % de los clientes tras entrega
- Registrar: la fila semanal de `bitacora/embudo.csv` y las ventas del día en `bitacora/ventas.csv`
- Siguiente paso: [Pasar el gate G0→1](../fases/fase-0/gate.md) · [Gates](gates.md)

## Fuentes

- [06 · Validación §V4 y §L2](../referencia/06-validacion-y-lazos-agenticos.md): 15 restaurantes, embudo de 4 cifras semanales, 10–20 %, pivotar antes de Fase 1; reglas de decisión.
- [00 · Plan maestro §Fase 0](../referencia/00-plan-maestro.md): lista de 10–15, horario, oferta gancho, riesgo #1.
- [07 · Puntos ciegos §5, §7, §8](../referencia/07-puntos-ciegos-y-riesgos.md): mercado 2026, CAC ~$650 + 8–10 h, SPEI contra entrega en Fase 0, ningún cliente > 25–30 %.
- [Fase 0 · Vender a chefs](../fases/fase-0/ventas.md): guion de 90 s, zonas, hoja de precios, tabla del embudo, esquema de `prospectos.csv`.
- [research/cobranza-b2b](../research/cobranza-b2b.md): remisión firmada, acuerdo de 1 página.

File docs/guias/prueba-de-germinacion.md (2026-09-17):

# Hacer la prueba de germinación (V1) de un lote de semilla

**En una línea:** 50 semillas, una toalla húmeda y 3–5 días te dicen si un costal se siembra, se reclama o se descarta antes de arriesgar una charola o comprar 5 kg; es el método V1 y la primera fila de tu trazabilidad.

!!! info "Antes de empezar"
    - **Tiempo:** 10 min de montaje + 3–5 días de espera + 10 min de conteo · **Costo:** $0 (toalla de papel, bolsa con cierre, plumón) · **Personas:** 1
    - **Necesitas:** 50 semillas por lote (200 + 200 si vas a validar la Opción A de [sanitización](sanitizar-semilla.md)) · toalla de papel · bolsa con cierre o recipiente con tapa · atomizador con agua potable · plumón indeleble · termómetro o termohigrómetro ($150–199, [Steren](https://www.steren.com.mx/casa-y-oficina/termometros-digitales)) · `bitacora/semilla.csv`
    - **Prerequisitos:** ninguno. Se hace **antes** de [Sembrar una charola](sembrar-una-charola.md), antes de comprar más de 1 kg a un proveedor nuevo y con **cada costal nuevo**: el girasol de CEDA es grado botanero y no trae certificado de germinación ([research/semillas](../research/semillas-sustrato-charolas.md)).

## Cuándo se hace y qué se acepta

| Situación | Muestra | Umbral de aceptación |
|---|---|---|
| Lote nuevo de cualquier proveedor, antes de la primera siembra | 50 semillas | **≥85 %** germinadas |
| Girasol y chícharo (semilla grande, grado alimento) | 50 semillas | **≥80 %** |
| Antes de comprar >1 kg, el costal de 5 kg o el bulto de CEDA | 50 semillas del kilo de prueba | mismo umbral; si pasa, compra |
| Validar la Opción A de sanitización (hipoclorito 20,000 ppm) en un lote | 200 tratadas vs 200 sin tratar | la tratada mantiene el umbral; si cae, ese lote va con Opción B |
| Cada costal nuevo, aunque sea el mismo proveedor | 50 semillas | mismo umbral (el lote cambia aunque el proveedor no) |

Un lote que no pasa **se reclama o se descarta; nunca se siembra "a ver qué pasa"** ([06 · V1](../referencia/06-validacion-y-lazos-agenticos.md)).

## Pasos

1. **Asigna el código de lote interno al costal.** Consecutivo `S001`, `S002`… escrito con plumón en el empaque el día que llega; en `bitacora/semilla.csv` anota proveedor, número de lote del proveedor, fecha de compra y si trae COA. *Criterio de listo:* el costal tiene código visible y su fila existe antes de abrirlo.
2. **Cuenta 50 semillas al azar.** Toma de distintos puntos del costal (arriba, en medio, al fondo), no solo de la superficie. *Criterio de listo:* 50 exactas sobre la mesa; anotaste la fecha.
3. **Humedece la toalla.** Atomiza con agua potable hasta que esté húmeda sin escurrir; extiende las semillas separadas, sin tocarse; dobla la toalla encima. *Criterio de listo:* al levantar la toalla no gotea y ninguna semilla queda seca.
4. **Mete en la bolsa o recipiente y etiqueta.** Sin cerrar hermético (deja aire); escribe `Sxxx`, especie y fecha. *Criterio de listo:* etiqueta legible; la bolsa no queda inflada ni sellada.
5. **Deja 3–5 días a temperatura ambiente, 18–24 °C, fuera del sol directo.** En diciembre–febrero usa el punto más cálido de la casa o el tapete térmico ([Germinar en invierno](germinar-en-invierno.md)): una prueba hecha a 12 °C reprueba lotes buenos. *Criterio de listo:* el termómetro junto a la bolsa marca entre 18 y 24 °C.
6. **Revisa cada día.** Mantén la toalla húmeda (atomiza si se seca) y retira cualquier semilla con pelusa. *Criterio de listo:* toalla húmeda todos los días; sin olor.
7. **Cuenta entre el día 3 y el 5** (las brassicas suelen estar listas al día 3; girasol, chícharo y betabel al día 5). Germinada = raíz blanca visible saliendo de la semilla. `% = germinadas ÷ 50 × 100`. *Criterio de listo:* tienes las dos cifras (probadas y germinadas) escritas antes de tirar la toalla.
8. **Decide y registra.** Pasa → siembra o compra; no pasa → reclama al proveedor o descarta. Girasol de CEDA: si ≥80 %, recompra costal de 5 kg ($140) o bulto ($24/kg); si no, quédate con Al Natural ($185/kg). *Criterio de listo:* la fila de `bitacora/semilla.csv` tiene `%` y `decision`.

!!! example "Dos resultados reales de ejemplo"
    - Rábano Champion `S003`: 43 de 50 germinadas → **86 % → pasa** (umbral 85 %).
    - Girasol CEDA `S001`: 39 de 50 → **78 % → no pasa** (umbral 80 %): reclamar o descartar y sembrar la semana con Al Natural (`S002`); repetir V1 con el siguiente kilo antes de decidir el costal de 5 kg.
    - Girasol CEDA `S004` (segundo kilo): 42 de 50 → **84 % → pasa**; se autoriza la recompra de 5 kg y arranca el A/B de [Fase 0 · Siembra](../fases/fase-0/siembra.md).

!!! tip "Muestreo en charola (el V1 continúa en producción)"
    En el lazo diario L1 cuenta la germinación de **1 charola marcada por lote**: pinta con plumón un cuadro de 10 × 10 cm en la orilla de la charola y cuenta cuántas semillas de ese cuadro emergieron al destape. Si en charola germina mucho menos que en la toalla, el problema está en tu proceso (riego, peso, temperatura), no en la semilla ([06 · L1 y V2](../referencia/06-validacion-y-lazos-agenticos.md)).

!!! warning "Errores típicos"
    - **Tomar las 50 semillas de la superficie del costal.** La semilla vieja o dañada se asienta; muestrea a distintas profundidades.
    - **Dejar secar la toalla un día** o **sellar la bolsa hermética** (pelusa y resultado inválido).
    - **Probar en un cuarto frío en enero** y descartar un lote bueno; mide la temperatura.
    - **Sembrar "porque urge" sin esperar el resultado.** Tres días de espera cuestan menos que 10 charolas que no germinan.
    - **Confiar en el porcentaje del costal anterior.** Cada costal es un lote; cada lote, su V1.

## Al terminar

- [ ] Costal con código `Sxxx` y fila en `bitacora/semilla.csv` (proveedor, lote del proveedor, fecha de compra, COA)
- [ ] 50 semillas contadas de distintos puntos del costal
- [ ] Temperatura de la prueba entre 18 y 24 °C, registrada
- [ ] Conteo hecho al día 3–5 con `%` calculado
- [ ] Decisión escrita: siembra, compra, reclamo o descarte
- **Registrar en `bitacora/semilla.csv`** (si no existe, créalo con este encabezado; es el "registro de semilla" de [research/inocuidad §5](../research/inocuidad-operativa.md) y el dato de entrada de V1):
  `lote_semilla,especie,proveedor,lote_proveedor,fecha_compra,coa,fecha_prueba,semillas_probadas,germinadas,pct_germinacion,decision,observaciones`
  Ejemplo: `S001,girasol,Mayoreo Online (CEDA),2026-08-B12,2026-09-14,no,2026-09-18,50,43,86,acepta,grado botanero; pedir sin tratamiento`
- **Siguiente paso:** [Sanitizar semilla](sanitizar-semilla.md) y [Sembrar una charola](sembrar-una-charola.md). Ficha completa del método en [Validación · V1](../validacion/v01-germinacion.md).

## Fuentes

- [06 · Validación y lazos agénticos](../referencia/06-validacion-y-lazos-agenticos.md): método V1 (50 semillas, 3–5 días, ≥85 % / ≥80 %), muestreo L1, esquema de datos.
- [research/inocuidad-operativa §2 y §5](../research/inocuidad-operativa.md): prueba 200 vs 200 para la Opción A, registro de semilla, COA y lote del proveedor.
- [research/semillas-sustrato-charolas](../research/semillas-sustrato-charolas.md) y [08 · Recetas](../referencia/08-recetas-y-economia-unitaria.md): girasol de CEDA (grado botanero, prueba obligatoria, recompra 5 kg / bulto), precios de semilla.
- [Fase 0 · Siembra](../fases/fase-0/siembra.md): semana 0 de V1 en el calendario de arranque.

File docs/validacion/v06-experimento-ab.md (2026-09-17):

# V6 · Protocolo de experimento A/B (mejora continua)

**En una línea:** un solo cambio a la vez, siempre con control, mínimo 3 charolas por brazo con posiciones alternadas, métrica primaria definida **antes** de sembrar, y el cambio entra al SOP solo si mejora ≥ 10 % esa métrica sin empeorar las secundarias; el agente L3 propone, tú ejecutas y el resultado se commitea.

!!! info "Antes de empezar"
    - **Cuándo:** cuando el informe L3 del domingo propone un experimento, cuando un KPI está en ámbar sin causa clara, o cuando quieres mover una receta (densidad, remojo, oscuridad, setpoint). **Máximo un experimento activo a la vez**; enero (cráter de ventas) es buen mes para correrlos · **Tiempo:** 1 ciclo de cultivo (7–18 días según especie) + 15 min de diseño + 15 min de análisis · **Costo:** el costo variable de 6 charolas (girasol CEDA $9.10; rábano $49.30; arúgula $35.30 c/u) · **Personas:** 1
    - **Necesitas:** un [V2](v02-rendimiento.md) aprobado de esa variedad (CV < 15 % en el control: si el proceso no está controlado, el A/B mide ruido); semilla de un solo lote; básculas; `bitacora/validacion/v06-experimentos.csv`; la plantilla de abajo
    - **Guías relacionadas:** [Sembrar una charola](../guias/sembrar-una-charola.md) · [Diseño · Datos §5 (el informe L3)](../diseno/datos.md) · [Software · Firmware → Cambiar setpoints](../software/firmware.md) · **Desbloquea:** cambiar el SOP, una densidad o un setpoint con un commit que cita la evidencia

## Propósito

Sin control, cualquier mejora es una anécdota: "esta semana rindió más" puede ser la semilla, el clima, la posición o el cambio que hiciste. El A/B aísla el cambio. Y el umbral del 10 % existe para no perseguir mejoras que caben dentro de la variación normal de tres charolas ([06 §V6](../referencia/06-validacion-y-lazos-agenticos.md)). Con el tiempo, el historial de experimentos + decisiones se vuelve el manual de operación real del huerto ([06 §L3](../referencia/06-validacion-y-lazos-agenticos.md)).

Ejemplos de la fuente: densidad **100 g vs 120 g** de girasol; remojo **8 h vs 12 h**; **3 vs 4 días** de oscuridad. El primero de la Fase 0 es semilla **CEDA vs Al Natural** a 135 g ([Fase 0 · Siembra](../fases/fase-0/siembra.md)).

## Reglas

| Regla | Por qué |
|---|---|
| **Un solo cambio** entre los dos brazos; todo lo demás idéntico (lote, densidad, sanitización, remojo, coco, día, riego) | Si cambian dos cosas no sabes cuál actuó |
| **Mínimo 3 charolas por brazo** (6 en total); mejor 4–5 si el rack lo permite | Con menos, una charola rara decide el resultado |
| **Posiciones alternadas** en la pila de oscuridad y en el rack (A/B/A/B/A/B), no un brazo por nivel | El nivel (luz, corriente de aire, boquilla) es un factor escondido |
| **Métrica primaria definida antes** de sembrar: g/charola o % de merma; una sola | Elegirla después es elegir la que salió bien |
| **Secundarias fijadas antes**: merma, CV, moho, días a cosecha, cáscaras pegadas, estiramiento | "No empeorar" solo se puede juzgar si están escritas |
| **Adoptar solo si mejora ≥ 10 %** la primaria y las secundarias del brazo de prueba no salen peor que las del control | Umbral de la fuente; por debajo es ruido |
| **Un experimento activo a la vez** | Dos A/B en el mismo rack se contaminan |
| **El agente propone; tú ejecutas; el resultado se commitea** | El agente nunca cambia densidades ni setpoints solo |

Tolerancia de las secundarias: la fuente pide "sin empeorar"; propuesta operativa: la secundaria del brazo de prueba no es peor que la del control **más allá del CV del control** medido en V2 `[POR VERIFICAR: 06 no fija tolerancia; ajustar con los primeros 3 experimentos]`.

## Procedimiento

1. **Escribe la hipótesis y la plantilla** (abajo) antes de tocar semilla: variable, brazo control (la receta actual del SOP), brazo prueba, n, métrica primaria, criterio de éxito (≥ 10 %), secundarias, fechas. Si el experimento viene del informe L3, copia su propuesta y ajusta lo que no sea viable. *Criterio de listo:* archivo `bitacora/experimentos/EXP-AAAAMMDD-nombre.md` con todos los campos llenos.
2. **Siembra los dos brazos el mismo día**, mismo lote `Sxxx`, alternando posiciones; etiqueta cada charola con su `siembra_id` y en `observaciones` `EXP-… brazo A` / `brazo B`. *Criterio de listo:* 6 filas en `bitacora/produccion.csv` con el `experimento_id` en observaciones.
3. **Trata igual a los dos brazos** durante el ciclo. Cualquier evento (riego a mano, mover una charola) se anota en las dos. *Criterio de listo:* cero diferencias no planeadas.
4. **Cosecha el mismo día, pesa cada charola** y registra las secundarias por charola (merma %, moho sí/no, días a cosecha). *Criterio de listo:* 6 pesos y 6 juegos de secundarias.
5. **Analiza**: media y CV por brazo; `mejora_pct = (media_prueba − media_control) ÷ media_control × 100` (con merma como primaria, la mejora es la **reducción**). Compara cada secundaria. *Criterio de listo:* fila en `v06-experimentos.csv`.
6. **Decide**: `adoptar` (≥ 10 % y secundarias OK), `rechazar`, o `repetir` (resultado entre 5 y 10 %, o CV del control > 15 %). *Criterio de listo:* decisión escrita con fecha.
7. **Si adoptas: commit al SOP.** La receta en tu copia de [08](../referencia/08-recetas-y-economia-unitaria.md) o de [Sembrar una charola](../guias/sembrar-una-charola.md), o el setpoint en `firmware/` con el `experimento_id` en el mensaje del commit. El agente ve el cambio la semana siguiente en el paquete de datos. *Criterio de listo:* hash del commit en la fila.

## Criterio de aceptación

!!! example "Adoptar el cambio solo si"
    - **≥ 3 charolas por brazo**, mismo lote, mismo día, posiciones alternadas, **un solo cambio**.
    - La métrica primaria (fijada antes) mejora **≥ 10 %** en el brazo de prueba respecto al control.
    - **Ninguna secundaria empeora** (merma, CV, moho, días a cosecha…).
    - El CV del brazo control es < 15 % (el proceso estaba controlado; si no, el experimento es inválido y primero se corre [V2](v02-rendimiento.md)).
    - El resultado y la decisión están en `v06-experimentos.csv` y, si se adopta, en un commit.

## Plantilla de experimento

Copia a `bitacora/experimentos/EXP-AAAAMMDD-nombre.md` y llénala **antes** de sembrar:

```markdown
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

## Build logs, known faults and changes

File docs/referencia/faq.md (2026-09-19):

# Preguntas frecuentes

**En una línea:** las preguntas que de verdad surgen al planear y operar el huerto, con respuesta
corta, el número que la sostiene y el enlace a la página donde está el "cómo".

Convención: la respuesta directa va en **negritas**; después, el porqué en dos líneas y la página
para ejecutarlo. Cifras en MXN al 12-sep-2026.

## Arranque

### ¿Puedo empezar sin túnel?

**Sí; así está diseñada la Fase 0.** Un rack de 5 niveles bajo techo con luz indirecta, 20 charolas
y semilla ($8,814 en total) valida en 6 semanas si hay quien compre. El túnel ($41,634) solo
se compra al pasar el gate G0→1 (2 clientes con 3 compras semanales seguidas y margen ≥ 55 %).
Ver [Fase 0](../fases/fase-0/index.md) y [Gate G0→1](../fases/fase-0/gate.md).

### ¿Qué hago la primera semana, antes de comprar nada?

**Seis acciones casi gratis:** escritura y condominio, pregunta al contador (¿socio/accionista?),
medidor de consumo eléctrico 7 días ($336.40), tandeo y EC/pH de la llave, aviso de huerto a la
alcaldía y el curso gratis de Intagri. Ver [Antes de gastar un peso](../empieza-aqui/antes-de-gastar-un-peso.md).

### ¿Cuánto cuesta cada fase de verdad?

**Fase 0 $8,814 · Fase 1 $41,634 · Fase 2 $27,251 (acumulado $77,699; $72,421 en versión austera).** El plan
original decía $60–90k porque no presupuestaba racks reales ($2,019 c/u), tubos T8, respaldo DC,
GFCI + tierra ni refrigerador. Tablas completas y CSV descargables en [BOM por fase](bom.md).

### ¿Cuánto tiempo real me va a tomar?

**~15 h/semana en régimen de Fase 1–2, no las 6–9 h del plan.** Siembra 3 h + cosecha/empaque
3.5–4.5 + lavado 1.5 + reparto 3–4 + ventas/cobranza 1.5–2 + sistema 1–1.5 + compras 1. La
automatización quita riego, ventilación y vigilancia, pero no siembra, corta, reparte ni cobra.
Mídelo 4 semanas con el [Timesheet semanal](../guias/timesheet-semanal.md) (V9); si pasas de 18 h
tres semanas seguidas, contratas ayudante ($1,300–1,600/mes por 6 h/sábado) o recortas clientes.

### ¿Qué tanto puedo escalar en 80 m²?

**El techo no son los m²: es la energía (250 kWh de DAC), tus horas y el agua (tandeo).** Orden de
escalamiento: subir precios y lista de espera → ayudante 4–8 h/sem → LED solo con contrato PDBT →
segunda ubicación o alianza con otro productor. Nunca renta sin 8+ clientes recurrentes en lista
de espera por 2 meses. Ver [07 §14](07-puntos-ciegos-y-riesgos.md) y [Fase 3](../fases/fase-3/index.md).

## Legal y fiscal

### ¿Qué pasa si mi patio es condominio?

**Revisa la escritura antes de invertir un peso en el túnel.** El art. 21 de la Ley de Propiedad en
Condominio prohíbe usos distintos a la Escritura Constitutiva y el art. 23 hace comunes las azoteas:
un túnel en área común de uso exclusivo requiere acuerdo de asamblea y un solo vecino ante PROSOC
puede obligarte a desmontarlo. Patio privativo sin prohibición: adelante, avisa por escrito y usa
bomba DC (casi inaudible). Ver [Antes de gastar un peso §1](../empieza-aqui/antes-de-gastar-un-peso.md)
y [normativa](normativa.md).

### ¿Necesito licencia de COFEPRIS?

**No existe licencia sanitaria para vegetales frescos.** Lo único plausible es el Aviso de
Funcionamiento COFEPRIS-05-018: gratuito, en línea, sin aprobación y sin caducidad; preséntalo al
empezar a cortar y empacar de forma habitual (inicio de Fase 1). Mientras vendas charola viva, es una
planta viva. Ver [Aviso COFEPRIS](../guias/aviso-cofepris.md).

### ¿Puedo ser RESICO si soy socio o accionista de una empresa?

**No: el art. 113-E fracc. I de la LISR lo veta.** Opciones: facturar desde la empresa existente
(IVA 0 %, deduce toda la inversión), persona física en Actividades Empresariales, o que un familiar
no accionista opere y facture en RESICO AGAPES (solo si es real). Si NO eres socio: RESICO agrícola
= ISR $0 hasta $900k cobrados. Ver [normativa: árbol fiscal](normativa.md) y [Facturar CFDI](../guias/facturar-cfdi.md).

### ¿Tengo que cobrar IVA a los restaurantes?

**Facturas con IVA tasa 0 %** (vegetales no industrializados, art. 2-A LIVA; cortado y empacado
sigue siendo no industrializado). Tasa 0 % no es "exento": acreditas el IVA de tus insumos. Clave
`50404100`, unidad `KGM` o `H87`. Ver [Facturar CFDI](../guias/facturar-cfdi.md).

### ¿PUE o PPD? ¿Qué es el REP?

**PUE solo si te pagan dentro del mes de emisión; cualquier crédito que cruce de mes es PPD y obliga
a un complemento de pago (REP) a más tardar el día 5 del mes siguiente al cobro.** Un REP mensual
agrupado por cliente basta (30 min al mes); la multa por no emitirlo es de $22,300–127,530 por
comprobante. Ver [Cobrar y suspender](../guias/cobrar-y-suspender.md).

### ¿Qué etiqueta debe llevar mi producto?

**Ninguna obligatoria en B2B: la NOM-051 no aplica** (insumo, no preenvasado al consumidor; charola
viva es planta; corte a granel está excluido). Pon de todos modos etiqueta simple: marca, variedad,
fecha de cosecha, lote, contacto y "enjuagar antes de consumir". Solo si vendes clamshells cerrados
a retail entran NOM-051 y NOM-030. Ver [Cosechar y empacar](../guias/cosechar-y-empacar.md).

### ¿Necesito seguro?

**No por ley; a esta escala te autoaseguras** (fondo de $500/mes hasta $10k + inocuidad
documentada). Cotiza RC de producto (GNP RC PyMEs, GMX; ~$3,000–8,000/año aprox.) solo cuando un
hotel o cadena lo pida en su alta de proveedor. Declara la actividad a tu aseguradora de casa para
que no rescindan la póliza. Ver [07 §11](07-puntos-ciegos-y-riesgos.md) y [normativa](normativa.md).

### ¿Aplico a Altépetl o a Cosecha de Lluvia?

**Altépetl no (solo suelo de conservación); Cosecha de Lluvia sí, si tu colonia está en la
convocatoria** (histórico: Iztacalco, Iztapalapa, Tláhuac, Tlalpan, V. Carranza, Xochimilco y otras).
Convocatoria enero–febrero; prepara INE, CURP, comprobante ≤ 3 meses y predial. Te instalan un
sistema de ~$20k gratis. Ver [Aplicar a Cosecha de Lluvia](../guias/aplicar-cosecha-de-lluvia.md).

## Producción

### ¿Qué semilla de girasol compro?

**Las dos, y corres una prueba A/B:** 1 kg de CEDA ($34, grado alimento) contra 1 kg específico
para microgreens ($185, Al Natural). Si la de CEDA germina ≥ 80 % (V1), la recompra es costal de
5 kg ($140) o bulto ($24/kg) y la semilla baja de ~$25 a ~$4.60 por charola. Ver
[Prueba de germinación](../guias/prueba-de-germinacion.md) y [08-recetas](08-recetas-y-economia-unitaria.md).

### ¿Por qué no arrancar con chícharo si es "barato"?

**Porque lleva 275 g por charola: $93.50 solo de semilla a $340/kg (Hydroenv) contra un precio de
venta de $90–120.** Pierde dinero a cualquier precio ≤ $98. Solo entra cuando consigas arvejón grado
alimento en CEDA (~$40–60/kg, por validar). Arranca con girasol + rábano + arúgula. Ver
[08-recetas](08-recetas-y-economia-unitaria.md).

### ¿Necesito lámparas?

**En Fase 0 no; en Fase 1 sí conviene.** Con buena luz indirecta se produce todo el año (nov–feb es
la época más soleada; el día más corto dura 10 h 58 min). Para 25–35 charolas/semana parejas en un
rack de 4 niveles: 8 tubos T8 18 W 6500K estándar ($121 c/u, JWJ) + canaletas ≈ $1,400, 12–14 h/día,
~$60–90/mes de luz. No pagues "grow lights" para un cultivo de 10 días. Ver [clima](clima.md).

### ¿Cómo sé si es moho o son raíces normales?

**Pelos blancos, uniformes y sin olor sobre la raíz = normal; telaraña gris/verde/negra con olor
fétido = moho: la charola se tira sin negociar.** Umbral V8: > 10 % de charolas afectadas dispara
H2O2 en desinfección, más ventilación y −10 % de densidad. Ver [Control de plagas](../guias/control-de-plagas.md)
y [V8 Sanitaria](../validacion/v08-sanitaria.md).

### ¿Puedo germinar en invierno?

**Sí, con tapete térmico (~$250–450 aprox.) o el punto más cálido de la casa.** De diciembre a
febrero las noches de 5–9 °C alargan un ciclo de 8–10 días a 12–16 y girasol/chícharo fríos se
pudren; a 22 °C con ESP32 + relé + tapete el "cuarto de germinación" cuesta < $1,000. Ver
[Germinar en invierno](../guias/germinar-en-invierno.md).

### ¿Qué hago con el sustrato usado?

**Sale del área de producción el mismo día de cosecha:** composta propia en tambo (alimenta las
camas de Fase 3), huertos comunitarios (contactos en la Escuela de Huertos Urbanos de SEDEMA) o
recolección de orgánicos de la alcaldía. Son 100–150 kg/mes de coco con raíces; mal manejado cría
mosca fungosa. Charola con fusarium: bolsa cerrada a la basura, nunca a la composta. Ver
[07 §12](07-puntos-ciegos-y-riesgos.md).

### ¿Necesito refrigerador?

**Solo si vendes cortado: sí, dedicado y a 4–5 °C desde la primera hora.** A 5 °C el microgreen
cortado dura 14 días; a 10 °C, 4; a 20–25 °C, menos de 1. Usado de 9–11 pies (~$4,000 aprox.) y
hielera de 45–50 L con gel packs para el reparto (< 10 °C por 4–6 h). La charola viva evita todo
esto: es el formato preferente. Ver [Cosechar y empacar](../guias/cosechar-y-empacar.md).

### ¿Cómo sanitizo la semilla y por qué?

**Girasol y chícharo siempre: H2O2 al 3 % a 60 °C, 5 min con agitación, enjuague.** El remojo tibio
de 8–24 h es una incubadora de *Salmonella*/*E. coli* si la semilla venía contaminada. Para clientes
hotel: hipoclorito de calcio 20,000 ppm (31 g/L del 65 %), 15 min, triple enjuague. Ver
[Sanitizar semilla](../guias/sanitizar-semilla.md).

## Agua y clima

### ¿Puedo usar agua de la llave para el NFT?

**Depende de la EC de tu colonia: mídela 3 días distintos antes de diseñar la nutrición.** < 0.4
mS/cm (poniente/centro, Cutzamala): directo con carbón activado para el cloro; 0.4–0.8: mezcla 50/50
con lluvia; > 0.8 (oriente/sur, pozos): lluvia como fuente principal o RO. Para microgreens la red
sirve casi en toda la ciudad. Ver [Fase 1 → Agua](../fases/fase-1/agua.md) y [V7 Agua](../validacion/v07-agua.md).

### ¿Qué tan grande debe ser el tinaco?

**750 L (Rotoplas Resistec, $2,051) si tu colonia no tiene tandeo; 1,100 L ($3,774) si está en
Tlalpan, Iztapalapa, Xochimilco, Tláhuac o Milpa Alta.** Regla: el sistema corre 100 % desde tinaco
propio con autonomía ≥ 2 semanas (consumo 1–3 m³/mes); la red solo rellena. Consulta tu colonia en
Agua en tu Colonia (SACMEX). Ver [Fase 1 → Agua](../fases/fase-1/agua.md).

### ¿Tengo que poner malla antigranizo?

**Sí, sin excepciones, desde Fase 1 y montada 10–20 cm por encima del plástico.** Tacubaya registra
2–3 días de granizo al año, pero es hiperlocal, hay 5–6 eventos severos por temporada y el pico es
**agosto**: ponla antes de mayo y no la quites antes de octubre. ~40 m × $40/m = $1,600. Ver
[Tensar plástico y mallas](../guias/tensar-plastico-y-mallas.md) y [clima](clima.md).

### ¿Me afectan las heladas?

**Solo en el sur alto (Tlalpan, Xochimilco, Milpa Alta): mínimas extremas de −1 a −4 °C en dic–feb; en
centro/norte/poniente prácticamente no hiela.** Una sola helada mata el NFT de albahaca: túnel
cerrado de noche, alarma < 6 °C, masa térmica o calefactor de 500 W en relé las ~10 noches críticas.
Ver [clima](clima.md).

### ¿Qué cambia en la temporada de lluvias?

**HR de 70–89 % de junio a septiembre = hongos garantizados sin ventilación.** Ventilador por
histéresis de HR > 70 % (la automatización más importante), sembrar ~10 % menos denso, riego solo por
abajo, Gnatrol comprado antes de junio y trampas amarillas. Lado bueno: 8,800–17,500 L/año de agua
casi destilada del techo. Ver [clima](clima.md).

## Eléctrico

### ¿Por qué no la bomba periférica de 0.5 HP del plan?

**Porque consume 370–450 W las 24 h ≈ 324 kWh/mes: te manda a tarifa DAC ella sola (~$2,600/mes de
recibo).** Para 6–8 líneas NFT bastan 8–16 L/min a < 2 m: bomba de diafragma 12 V de 40–60 W (~32
kWh/mes) colgada de la batería, o sumergible de 65 W. La periférica queda para trasiego. Ver
[07 §1](07-puntos-ciegos-y-riesgos.md).

### ¿Qué pasa si se va la luz?

**Con la arquitectura DC-first, nada: la bomba NFT de 12 V ya corre desde una batería LiFePO4 de
100 Ah en flotación (28–30 h continuas, ~2.5 días en modo 15/15).** Un UPS de PC no sirve (4–8 min
con una bomba de 450 W). Planea 3–6 cortes/año de 1–8 h. Router y cerebro van en UPS chico
($1,189) para que salgan las alertas. Ver [Armar el respaldo DC](../guias/armar-respaldo-dc.md) y
[Simulacro de apagón](../guias/simulacro-de-apagon.md).

### ¿De verdad necesito GFCI y tierra física?

**Sí: el patio es "lugar mojado" según la NOM-001-SEDE y es lo que evita electrocutar a alguien con
las manos mojadas.** Breaker Square D QO120GFI ($1,159) en el centro de carga o mínimo contacto
GFCI ($389) aguas arriba de todo, tapa intemperie "in-use" (~$249), varilla copperweld 5/8"×3 m con
≤ 25 Ω medidos, electrónica en IP65. Medio día de electricista ($1,500–3,500). Ver
[Instalar GFCI y tierra](../guias/instalar-gfci-y-tierra.md).

### ¿Cómo sé si voy a caer en DAC?

**Lee el promedio de 12 meses en tu recibo y súmale 85–90 kWh (Fase 2) + 25–40 kWh (refrigerador).**
< 220: adelante; 220–250: sin LED extra y alarma en HA a 220 kWh; > 250: contrato PDBT separado antes
de la Fase 2. Mide 7 días con el Steren HER-432 ($336.40). Ver [Antes de gastar un peso §3](../empieza-aqui/antes-de-gastar-un-peso.md).

### ¿Raspberry Pi o mini PC?

**Mini PC ThinkCentre usado i5/8 GB/SSD (~$3,000 aprox.) para HA + Grafana + Frigate; Pi 5 4 GB
($3,069, Cyberpuerta) si prefieres bajo consumo y GPIO.** Va dentro de casa (humedad y robo), con
UPS. Ver [Software](../software/index.md).

### ¿Y si me roban el equipo?

**Diseña "botín mínimo": cerebro y fuente dentro de casa; solo nodos ESP32 de $150 a la
intemperie** (reduce el botín 80 %), nada visible desde la calle, candado + cadena (~$600), ESP32-CAM
con detección nocturna desde Fase 1, equipo marcado y fotografiado. CDMX tiene la tasa de
victimización más alta del país. Ver [07 §10](07-puntos-ciegos-y-riesgos.md).

## Ventas y cobranza

### ¿A qué precio vendo?

**Charola viva girasol/chícharo $90–120 (lista), $70–80 por volumen; variedades finas $130–180;
clamshell 100 g a restaurante $50–90; hierbas de Fase 2 por manojo a $20–35 B2B.** Los $60–90 del
plan original solo como promoción del primer mes: a ese precio rábano deja 18 %, brócoli 5 % y
chícharo pierde. Ver [Hoja de precios](../guias/hoja-de-precios.md) y [08-recetas](08-recetas-y-economia-unitaria.md).

### ¿Cómo cobro?

**Fase 0: SPEI contra entrega, cero excepciones (estás validando que pagan, no que quieren). Fase 1:
factura semanal, pago a 7 días. Crédito a 15 días solo ganado (8+ semanas puntuales) con tope de 2
semanas de pedidos.** Remisión firmada en cada entrega; ningún cliente > 25–30 % de las ventas. Ver
[Cobrar y suspender](../guias/cobrar-y-suspender.md).

### ¿Qué hago si un restaurante no paga?

**Regla 7/14/45:** día 0 recordatorio con la factura; +3 llamada al administrador; +7 siguiente
entrega solo de contado; +14 pausa total y pagaré por el saldo; +45 incobrable documentado (en RESICO
no pagaste ISR por lo no cobrado). Señales de alerta: pide más volumen y más plazo a la vez, pagos
parciales, cambia la razón social, restaurante con < 6 meses pidiendo crédito. Ver
[Cobrar y suspender](../guias/cobrar-y-suspender.md).

### ¿Con quién firmo: con el chef o con el dueño?

**Con el administrador o dueño, nunca solo con el chef** (la rotación de chefs es el riesgo #4 del
plan). Acuerdo de suministro de 1 página en cuanto un cliente pase de 3 semanas comprando: fresh
sheet dominical, pedido mínimo, rechazo solo en recepción, pago a 7 días, moratorios pactados.
Ver [Visitar a un chef](../guias/visitar-a-un-chef.md) y [Fase 2 → Clientes y cobranza](../fases/fase-2/clientes-y-cobranza.md).

### ¿Cuántas visitas necesito para cerrar un cliente?

**~15 visitas para 2–3 clientes recurrentes (conversión 10–20 %), ~$650 y 8–10 h por cliente.**
Muestra física gratis, martes–jueves 10–12, cocina de autor, brunch, pokés y coctelería en radio de
5 km. Registra el embudo cada semana (visitados → probaron → pidieron → recurrentes); si tras 15
visitas hay 0 recurrentes, pivota antes de la Fase 1. Ver [Fase 0 → Ventas](../fases/fase-0/ventas.md).

### ¿Qué pasa en enero?

**Enero es un cráter: modela −35 % de ingreso en enero–febrero y −20 % en Semana Santa.** Muchos
restaurantes de autor cierran del 24-dic al 6-ene y el sector en 2026 está contraído. El colchón sale
de noviembre–diciembre; suma un canal no-restaurante (suscripción a hogares ~$260/semana por 3
clamshells, mercados de productores) para que ninguno pese > 60 %. Ver [07 §5](07-puntos-ciegos-y-riesgos.md).

## Operación y automatización

### ¿El sistema aguanta si me voy de vacaciones?

**Riego, ventilación y alarmas sí (3–4 días, validado con V5); cosechar, empacar y entregar no.**
Si faltas un jueves ese ingreso no existe y el chef prueba otro proveedor: desde el mes 4, ayudante
de 6 h/sábado con SOP escrito. Ver [V5 Ausencia](../validacion/v05-ausencia.md) y [07 §13](07-puntos-ciegos-y-riesgos.md).

### ¿Qué sonda de pH compro?

**En dos etapas: PH-4502C ($329) para desarrollar y probar el lazo; kit DFRobot Gravity ($1,250)
cuando el NFT ya venda.** El electrodo caduca en 12–18 meses aunque no se use: no lo compres antes
de tiempo y presupuesta ~$1,050/año de calibración + sonda. Calibración quincenal con buffers
4.01/6.86 y patrón EC 1.413. Ver [Calibrar sondas pH/EC](../guias/calibrar-sondas-ph-ec.md).

### ¿Cada cuánto cambio la solución del NFT?

**Cambio completo cada 2–3 semanas aunque la EC "se vea bien"** (los micronutrientes se
desbalancean), relleno con agua de lluvia o filtrada, depósito a la sombra a 18–22 °C, filtro malla
120 en el retorno. Ver [Cambiar la solución NFT](../guias/cambiar-solucion-nft.md).

### ¿Qué pruebo antes de poner la primera planta bajo el sistema?

**72 h de dry-run con agua sola inyectando fallas** (bomba desconectada, tinaco < 20 %, línea
pellizcada, ESP32 apagado, Wi-Fi caído 30 min): 100 % de alarmas correctas o no entra en producción.
Ver [V3 Dry-run](../validacion/v03-dry-run.md).

### ¿Qué es un gate y qué pasa si no lo alcanzo?

**Un criterio Go/No-Go medible escrito antes de empezar la fase; no se renegocia a la baja: se itera
o se detiene.** G0→1: 2 clientes con 3 compras seguidas + margen ≥ 55 %; G1→2: 4–5 clientes fijos,
demanda insatisfecha 2 semanas y v1 estable 30 días; G2→3: neto ≥ $12k/mes por 3 meses con ≤ 9 h/sem.
Ver [Gates](../validacion/gates.md).

### ¿Dónde compro la electrónica?

**Un pedido grande a UNIT Electronics (ESP32, sensores, relés), hidráulica por Mercado Libre Full,
pack de capacitivos por Amazon y una ida a AG Electrónica (Rep. de El Salvador 20-F, Centro) por
gabinetes, cable y para conocer al proveedor de emergencia mismo día.** Ver [01 §3](01-proveedores-cdmx.md).

### ¿Qué leo primero?

**Gratis hoy: curso Intagri de hortalizas de hoja en NFT (en promoción a $0), manual del Kit Tláloc
y los manuales FAO. Compra: *Microgreens: The Insiders Secrets* (Donny Greens, $396.60) antes de
visitar chefs y *El jardinero horticultor* (Fortier, $488 en El Péndulo).** Ver
[Libros](../aprendizaje/libros.md), [Cursos](../aprendizaje/cursos.md) y [Videos](../aprendizaje/videos.md).

## Fuentes

[00-plan-maestro](00-plan-maestro.md) · [02-restricciones-y-requisitos](02-restricciones-y-requisitos.md) ·
[06-validacion-y-lazos-agenticos](06-validacion-y-lazos-agenticos.md) · [07-puntos-ciegos-y-riesgos](07-puntos-ciegos-y-riesgos.md) ·
[08-recetas-y-economia-unitaria](08-recetas-y-economia-unitaria.md) · [bom](bom.md) · [normativa](normativa.md) · [clima](clima.md) ·
informes: [puntos-ciegos](../research/puntos-ciegos.md) · [cobranza-b2b](../research/cobranza-b2b.md) · [normativa-fiscal](../research/normativa-fiscal.md) · [clima-agronomia](../research/clima-agronomia.md) · [electrico-respaldo-seguridad](../research/electrico-respaldo-seguridad.md) · [recetas-produccion-economia](../research/recetas-produccion-economia.md).

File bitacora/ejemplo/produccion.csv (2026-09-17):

siembra_id | fecha_siembra | variedad | lote_semilla | densidad_g | dias_oscuridad | fecha_cosecha | rendimiento_g | merma_pct | destino | precio_mxn | observaciones
GIR-260921-S001-R1N1 | 2026-09-21 | girasol | S001 | 135 | 3 | 2026-10-02 | 420 | 5 | muestra | 0 | A/B brazo CEDA; V1 88%; H2O2 3% 60C 5min; remojo 8h; muestra RestA
GIR-260921-S001-R1N2 | 2026-09-21 | girasol | S001 | 135 | 3 | 2026-10-02 | 0 | 100 | basura | 0 | A/B brazo CEDA; moho verde dia 6 (cascara sucia); tirada
GIR-260921-S002-R1N3 | 2026-09-21 | girasol | S002 | 135 | 3 | 2026-10-02 | 455 | 3 | muestra | 0 | A/B brazo Al Natural; V1 94%; muestra RestC (entregada 10-06)
GIR-260921-S002-R1N4 | 2026-09-21 | girasol | S002 | 135 | 3 | 2026-10-02 | 470 | 2 | casa | 0 | A/B brazo Al Natural; multiplicador 3.5x; se come en casa
AMA-260921-S005-R1N5 | 2026-09-21 | amaranto | S005 | 10 | 3 | 2026-10-06 | 150 | 10 | casa | 0 | prueba de color: sale VERDE; no vender como fino
RAB-260924-S003-R1N4 | 2026-09-24 | rabano | S003 | 28 | 2 | 2026-10-02 | 260 | 0 | muestra | 0 | V2 charola 1 de 3; sin remojo; muestra RestB
RAB-260924-S003-R1N5 | 2026-09-24 | rabano | S003 | 28 | 2 | 2026-10-02 | 275 | 0 | casa | 0 | V2 charola 2 de 3
RAB-260924-S003-R1N2 | 2026-09-24 | rabano | S003 | 28 | 2 | 2026-10-02 | 250 | 2 | casa | 0 | V2 charola 3 de 3; CV 4.8% OK
ARU-260924-S004-R1N1 | 2026-09-24 | arugula | S004 | 11 | 4 | 2026-10-06 | 230 | 3 | muestra | 0 | sin remojo; riego solo por fondo; muestra RestD
GIR-260928-S001-R1N1 | 2026-09-28 | girasol | S001 | 135 | 3 | 2026-10-09 | 435 | 4 | RestA | 105 | primer pedido cobrado; SPEI mismo dia; remision 001
GIR-260928-S001-R1N2 | 2026-09-28 | girasol | S001 | 135 | 3 | 2026-10-09 | 410 | 6 | RestA | 105 | remision 001
RAB-261001-S003-R1N4 | 2026-10-01 | rabano | S003 | 28 | 2 | 2026-10-09 | 270 | 0 | RestA | 155 | remision 001
ARU-261001-S004-R1N3 | 2026-10-01 | arugula | S004 | 11 | 4 | 2026-10-13 | 240 | 2 | RestB | 150 | primer pedido RestB; remision 002
GIR-261005-S001-R1N1 | 2026-10-05 | girasol | S001 | 135 | 3 | 2026-10-16 | 440 | 3 | RestA | 105 | remision 003
GIR-261005-S001-R1N2 | 2026-10-05 | girasol | S001 | 135 | 3 | 2026-10-16 | 425 | 5 | RestB | 105 | remision 004
GIR-261005-S001-R1N3 | 2026-10-05 | girasol | S001 | 135 | 3 | 2026-10-16 | 430 | 4 | RestC | 105 | pedido unico para brunch; remision 005
GIR-261005-S001-R1N5 | 2026-10-05 | girasol | S001 | 135 | 3 |  | 0 | 100 | basura | 0 | apilada 4 dias por descuido: moho; tirada dia 7
RAB-261008-S003-R1N4 | 2026-10-08 | rabano | S003 | 28 | 2 | 2026-10-16 | 265 | 0 | RestA | 155 | remision 003
RAB-261008-S003-R1N5 | 2026-10-08 | rabano | S003 | 28 | 2 | 2026-10-16 | 280 | 0 | RestB | 155 | remision 004; chef: perfecto
ARU-261008-S004-R1N3 | 2026-10-08 | arugula | S004 | 11 | 4 | 2026-10-20 | 235 | 3 | RestB | 150 | remision 006
GIR-261012-S001-R1N1 | 2026-10-12 | girasol | S001 | 135 | 3 | 2026-10-23 | 445 | 2 | RestA | 105 | remision 007
GIR-261012-S001-R1N2 | 2026-10-12 | girasol | S001 | 135 | 3 | 2026-10-23 | 415 | 5 | RestA | 105 | remision 007
RAB-261015-S003-R1N4 | 2026-10-15 | rabano | S003 | 28 | 2 | 2026-10-23 | 255 | 0 | RestA | 155 | remision 007; tallo largo: probar 1 dia menos de oscuridad
RAB-261015-S003-R1N5 | 2026-10-15 | rabano | S003 | 28 | 2 | 2026-10-23 | 270 | 0 | RestB | 155 | remision 008
ARU-261015-S004-R1N3 | 2026-10-15 | arugula | S004 | 11 | 4 | 2026-10-27 | 245 | 2 | RestB | 150 | remision 009
GIR-261019-S001-R1N1 | 2026-10-19 | girasol | S001 | 135 | 3 | 2026-10-30 | 450 | 2 | RestA | 105 | remision 010
GIR-261019-S001-R1N2 | 2026-10-19 | girasol | S001 | 135 | 3 | 2026-10-30 | 435 | 3 | RestB | 105 | remision 011
RAB-261022-S003-R1N4 | 2026-10-22 | rabano | S003 | 28 | 1 | 2026-10-30 | 265 | 0 | RestA | 155 | V6 brazo B: 1 dia de oscuridad; remision 010
RAB-261022-S003-R1N5 | 2026-10-22 | rabano | S003 | 28 | 2 | 2026-10-30 | 275 | 0 | casa | 0 | V6 control: 2 dias; sin comprador esta semana
GIR-261026-S001-R1N1 | 2026-10-26 | girasol | S001 | 135 | 3 |  |  |  |  |  | en rack; para pedido RestA de 3 charolas

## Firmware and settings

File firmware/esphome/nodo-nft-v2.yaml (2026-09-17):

# =============================================================================
#  HomeGreen · firmware/esphome/nodo-nft-v2.yaml
#  Nodo NFT v2 (Fase 2) · ESP32 DevKit V1 30 pines · ESPHome >= 2025.1
#  Alimentado desde el BUS DE BATERÍA (F3 de la fusiblera): sigue midiendo,
#  dosificando y avisando durante un corte de CFE.
#
#  Qué hace este nodo (lazos L0 locales; HA solo avisa, escala y optimiza):
#    · pH y EC de la solución (sondas en el RETORNO), con calibración de 2 puntos
#      (buffers 4.01 / 6.86), patrón EC 1.413 mS/cm y compensación de temperatura.
#    · Dosificación por histéresis con TIEMPO MUERTO de mezcla (10–15 min):
#      dosis fija pequeña → esperar → re-medir. Orden A → mezcla → B → mezcla → pH−.
#      Interlocks: nivel de tambo, bomba encendida y flujo real; tope de dosis/día;
#      sonda "no confiable" (salto > 1.5 pH en 5 min o voltaje fuera de rango).
#    · Continuidad del NFT: bomba principal con restore_mode RESTORE_DEFAULT_ON
#      (K1 por contacto NC: sin ESP32 la bomba corre), watchdog "bomba ON sin
#      flujo" que arranca la bomba de respaldo, detector de red CFE, voltaje de
#      batería y modo ahorro 15/15 (lo activa HA o tú).
#    · Llenado y purga del tambo con solenoides NC, con tiempo máximo de seguridad.
#    · Cada peristáltica se apaga sola a los 30 s como máximo (timeout físico en
#      firmware, aunque HA la haya encendido).
#    · Heartbeat: uptime, estado, señal Wi-Fi.
#
#  Tabla de pines (idéntica a docs/software/firmware.md; ver nota en electrico.md):
#    GPIO34  ADC1_CH6  placa pH PH-4502C (Po) vía RC 1 kΩ / 100 nF  (solo entrada)
#    GPIO35  ADC1_CH7  placa TDS SEN0244 (AOUT) vía RC             (solo entrada)
#    GPIO36  ADC1_CH0  divisor 47 kΩ / 10 kΩ del bus 12.8 V (×5.7) (solo entrada)
#    GPIO4   1-Wire    DS18B20 del tambo (TT-2), pull-up 4.7 kΩ
#    GPIO27  PCNT      YF-S201 caudal (≈ 450 pulsos/L) vía divisor 10k/20k (señal 5 V)
#    GPIO23  entrada   detector de red CFE (PC817 desde cargador USB), INPUT_PULLDOWN
#    GPIO25  MOSFET    peristáltica A (DP-1)
#    GPIO26  MOSFET    peristáltica B (DP-2)
#    GPIO33  MOSFET    peristáltica pH− (DP-3, AquAcid)
#    GPIO12  MOSFET    solenoide llenado SV-1 (½" NC)  ← pin de arranque: pull-down 10 kΩ OBLIGATORIO
#    GPIO13  MOSFET    solenoide purga   SV-2 (½" NC)
#    GPIO32  relé K1   bomba NFT principal P-1 por contacto NC (reposo = bomba ON)
#    GPIO14  relé K2   bomba NFT respaldo  P-2 por contacto NO
#    GPIO16  entrada   flotador "tambo alto"  (LT-2, opcional; INPUT_PULLUP, cierra a GND = lleno)
#    GPIO17  entrada   flotador "tambo bajo"  (LT-2, opcional; INPUT_PULLUP, cierra a GND = bajo)
#  Por qué GPIO32 para la principal y GPIO14 para el respaldo: GPIO14 emite un
#  pulso al arrancar el ESP32; en K2 (NO, normalmente apagado) ese pulso es un
#  parpadeo inofensivo del respaldo; en K1 sería un corte breve de la principal.
#  LT-2 no está en bom/fase2.csv [POR VERIFICAR: elegir flotador con contacto o un
#  segundo JSN-SR04T y agregarlo al BOM]; sin flotador, deja los pines al aire y
#  el interlock de nivel queda desactivado (ver "nivel_tambo_bajo").
#
#  Fuentes: docs/research/electrico-respaldo-seguridad.md §5 (base de este YAML),
#           docs/referencia/06-validacion-y-lazos-agenticos.md (L0, watchdogs),
#           docs/diseno/control.md (Lazos 2 y 4), docs/diseno/hidraulico.md §5.3 y §6,
#           docs/referencia/03-instalacion.md §2.2–2.3.
# =============================================================================

substitutions:
  nodo: nodo-nft-v2

esphome:
  name: ${nodo}
  # Sin friendly_name: los entity_id quedan como en docs/diseno/datos.md §2
  comment: "HomeGreen · pH/EC con dosificación por histéresis, continuidad DC-first del NFT"
  min_version: "2025.1.0"
  project:
    name: "homegreen.nodo_nft"
    version: "1.0.0"
  on_boot:
    priority: -100
    then:
      - lambda: |-
          const uint32_t ahora = millis();
          id(dosis_ventana_inicio_ms) = ahora;
          id(bomba_arranque_ms) = ahora;     // gracia para el watchdog de flujo tras un reinicio
          id(corte_inicio_ms) = ahora;       // referencia si el nodo arranca ya en batería
          ESP_LOGI("boot", "Nodo NFT v2 listo. Bomba principal=%s", id(bomba_nft).state ? "ON" : "OFF");
      # El detector de red tiene delayed_on: 5s; esperamos a que se asiente antes de
      # decidir si arrancamos en batería (reinicio en medio de un corte, simulacro V11).
      - delay: 10s
      - lambda: |-
          if (!id(red_cfe_presente).state) {
            id(en_corte) = true;
            ESP_LOGW("boot", "Arranque SIN red CFE: NFT en bateria (%.2f V)", id(voltaje_bateria_nft).state);
          } else {
            ESP_LOGI("boot", "Red CFE presente");
          }

esp32:
  board: esp32dev
  framework:
    type: esp-idf
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

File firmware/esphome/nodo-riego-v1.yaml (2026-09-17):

# =============================================================================
#  HomeGreen · firmware/esphome/nodo-riego-v1.yaml
#  Nodo de riego v1 (Fase 1) · ESP32 DevKit V1 30 pines · ESPHome >= 2025.1
#
#  Qué hace este nodo (lazos L0 locales: funcionan sin Wi-Fi ni Home Assistant):
#    · Riego de microgreens por histéresis con banda muerta, por nivel de rack
#      (4 capacitivos MT-1…4), con interlock por nivel de tinaco, máximo de
#      ciclos por hora y duración máxima por ciclo (watchdog "riego sin fin").
#    · Ventilación por histéresis de HR y T (SHT31) con tiempo mínimo encendido
#      y forzado de 10 min cada hora, opcional, para la temporada de lluvia.
#    · Luces T8 con fotoperiodo local (sigue funcionando si HA está caído).
#    · Nivel del tinaco (JSN-SR04T) en % y litros; temperatura del agua (DS18B20).
#    · Heartbeat: uptime, estado del nodo, señal Wi-Fi, IP y versión.
#
#  Home Assistant NO es requisito para que este nodo riegue o ventile: solo
#  expone setpoints (number/select/switch), grafica y avisa. Regla del proyecto:
#  "una capa solo escala problemas hacia arriba" (docs/referencia/06 §L0).
#
#  Tabla de pines (idéntica a docs/diseno/electrico.md y docs/software/firmware.md;
#  si cambias uno, cámbialo en los tres lugares):
#    GPIO32  ADC1_CH4  MT-1 capacitivo nivel 1 (rack)
#    GPIO33  ADC1_CH5  MT-2 capacitivo nivel 2
#    GPIO34  ADC1_CH6  MT-3 capacitivo nivel 3 (solo entrada)
#    GPIO35  ADC1_CH7  MT-4 capacitivo nivel 4 (solo entrada)
#    GPIO21  SDA       SHT31 T/HR ambiente (dirección 0x44)
#    GPIO22  SCL       SHT31
#    GPIO4   1-Wire    DS18B20 del tinaco (pull-up 4.7 kΩ a 3V3)
#    GPIO5   TRIG      JSN-SR04T nivel de tinaco (TRIG acepta 3.3 V)
#    GPIO18  ECHO      JSN-SR04T (ECHO es de 5 V: divisor 10 kΩ / 20 kΩ obligatorio)
#    GPIO25  K1        bomba diafragma 12 V (riego por nebulizadores)  ┐ módulo relé
#    GPIO26  K2        ventilador 12 V                                 │ 4 canales,
#    GPIO27  K3        luces T8 127 V (K3 excita el relé de potencia K5)│ activo en bajo
#    GPIO14  K4        reserva: tapete térmico dic–feb o luz del nivel 5┘ (inverted: true)
#  Solo ADC1 (GPIO32–39) para analógicos: ADC2 deja de funcionar con Wi-Fi activo.
#
#  Fuentes: docs/referencia/06-validacion-y-lazos-agenticos.md (lazos L0, watchdogs),
#           docs/diseno/control.md (setpoints y bandas), docs/diseno/electrico.md (pines),
#           docs/referencia/03-instalacion.md §1.3.
# =============================================================================

substitutions:
  nodo: nodo-riego-v1
  # --- Calibración de los capacitivos (volts leídos en "MT-n voltaje") ---------
  # Procedimiento (docs/software/firmware.md → "Calibrar sensores"):
  #   seco   = voltaje con el sensor AL AIRE, limpio y seco            → 0 %
  #   humedo = voltaje con el sensor sumergido HASTA LA LÍNEA en agua  → 100 %
  # Cada pieza del pack es distinta (20–30 % salen malas o desviadas): calibra
  # las cuatro por separado. Los valores de abajo son de EJEMPLO
  # [POR VERIFICAR: mide los tuyos y sustitúyelos antes del dry-run V3].
  mt1_seco: "2.80"
  mt1_humedo: "1.30"
  mt2_seco: "2.80"
  mt2_humedo: "1.30"
  mt3_seco: "2.80"
  mt3_humedo: "1.30"
  mt4_seco: "2.80"
  mt4_humedo: "1.30"

esphome:
  name: ${nodo}
  # Sin friendly_name a propósito: así los entity_id en Home Assistant quedan
  # exactamente como en docs/diseno/datos.md §2 (sensor.humedad_sustrato_n1, …).
  comment: "HomeGreen · riego por histéresis, ventilación por HR, luces T8, nivel de tinaco"
  min_version: "2025.1.0"
  project:
    name: "homegreen.nodo_riego"
    version: "1.0.0"
  on_boot:
    priority: -100        # todo inicializado; los relés ya arrancaron en OFF
    then:
      - lambda: |-
          id(vent_inicio_ms) = millis();
          ESP_LOGI("boot", "Nodo riego v1 listo. Actuadores en estado seguro (OFF); riego auto=%s",
                   id(riego_auto).state ? "ON" : "OFF");

esp32:
  board: esp32dev
  framework:
    type: esp-idf         # framework recomendado en ESPHome 2025+; "arduino" también compila

# -----------------------------------------------------------------------------
# Red. reboot_timeout: 0s en wifi y api: el nodo NUNCA se reinicia por perder
# el Wi-Fi o a HA (un reinicio cada 15 min resetearía los contadores del riego).
# -----------------------------------------------------------------------------
wifi:
  ssid: !secret wifi_ssid
  password: !secret wifi_password
  power_save_mode: none   # latencia baja; el nodo va a 12 V, no a batería de botón
  reboot_timeout: 0s
  ap:                     # red de rescate si no encuentra tu Wi-Fi (conéctate y usa el portal)
    ssid: "${nodo} rescate"
    password: !secret ap_password

captive_portal:

api:
  encryption:
    key: !secret api_key_riego
  reboot_timeout: 0s

ota:
  - platform: esphome
    password: !secret ota_password

logger:
  level: INFO
  baud_rate: 115200
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

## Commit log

2026-09-12 Add CDMX supplier catalog, requirements, tools, learning resources, BOMs and research reports
    - docs/01: curated supplier guide with verified prices and buy links
    - docs/02: real constraints (climate at 2,240 m, water/tandeo, tax/sanitary)
    - docs/04-05: tools per phase and learning path (tutorials, books, courses)
    - bom/: per-phase BOM CSVs with links and price status
    - docs/research/: 11 full research reports (12-sep-2026)
    - Corrections folded into master plan and installation docs:
    sanitary PVC (not sch-40), submersible pump for NFT, hole-saw sizing,
    market-corrected price list, real rack costs
    Claude-Session: https://claude.ai/co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
    [fase0.csv, fase1.csv, fase2.csv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]
2026-09-12 Add blind-spots and risks doc with hard numbers (DAC tariff, cold chain, real hours, market 2026)
    Claude-Session: https://claude.ai/code/session_01KTf7VBDAoJPFLBjDXNEeXH
2026-09-12 Add production recipes doc, fold gap research into docs (sanitization, DC-first backup, anchoring, B2B collections) and fix dead links
    - docs/08: per-species recipes and unit economics ($/charola-semana ranking;
    chicharo with HE seed loses money — CEDA arvejon required)
    - docs/03: seed sanitization step, anchor procedure (placa + 4 anclas 3/8),
    GFCI/tierra fisica requirement, DC-first NFT backup architecture, critical path
    - docs/06: V10 mock recall, V11 monthly power-cut drill, lot-code format
    - docs/07: full B2B payment/collections section, corrected backup numbers
    - docs/02: PUE/PPD/REP mechanics; docs/01: seed price completions, labs, backup suppliers
    - BOMs updated (fase2 now incl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
    [fase0.csv, fase2.csv]
2026-09-15 Scaffold MkDocs Material wiki: site config, entry README, docs moved to referencia/
    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
2026-09-15 WIP wiki: first hydraulic P&ID diagrams and electrical schematic generator
    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
2026-09-15 WIP wiki: electrical schematics, P&ID, patio layouts, OpenSCAD models and renders, design pages
    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
    [linea_nft.scad, patio_fase2.scad, rack_charolas.scad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]
2026-09-15 WIP wiki: validation section, reference pages, learning pages, electrical and commercial guides
    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
    [produccion.csv, tunel_3x6.scad, ventas.csv]
2026-09-16 Add CLI tooling docs, CI workflows, and reconcile pins and links
    Completes the software/tooling slice of the wiki and runs the integration
    and consistency passes over the whole site.
    Tooling and CI:
    - tools/check_links.py: verify every external URL in docs/ and README.
    - tools/README.md and docs/software/herramientas-cli.md: document the four
    scripts, their options, and the bitacora conventions they depend on.
    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
    [cobranza.csv, costos.csv, timesheet.csv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]
2026-09-18 Rehacer el BOM sin duplicados y agregar la ruta de compra presencial
    El BOM eran tres CSV con una fila TOTAL escrita a mano, y eso permitia tres
    cosas que costaban dinero de verdad:
    1. Sumar ALTERNATIVAS como si fueran compras. La sonda de pH aparecia dos
    veces (la economica de $329 y el kit DFRobot de $1,250) y el total
    cobraba las dos, aunque la propia pagina de compras dijera "sin DFRobot".
    2. Cobrar DOS VECES entre fases. El no-break y la partida de seguridad
    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
    [fase0.csv, fase1.csv, fase2.csv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]
2026-09-18 Hacer legibles los diagramas: menos lienzo, mas tipografia y halo blanco
    El problema, medido en el navegador y no a ojo: Material limita la columna de
    contenido y los planos de patio median 1600 px, asi que se dibujaban al 43 %.
    Una cota de 10.5 unidades llegaba al ojo a 5.97 px, cuando el texto de la wiki
    es de 16 px. No eran "un poco chicos": eran un borron.
    Se atacó por tres lados, porque ninguno bastaba solo:
    1. CSS (commit anterior): la columna sube de 688 a 980 px. Ahi se acaba lo que
    se puede hacer con CSS: entre la columna y la tabla de contenidos quedan
    24 px, e invadir ese canal tapa justo la leyenda del plano.
    2. Menos lienzo. El panel derecho de los planos se comia 450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
    [alimentacion_esp32.py, bus_dc_first.py, nodo_nft_v2.py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]
2026-09-18 Propagar los totales nuevos a toda la wiki y calcular el escenario austero
    Quedaban 22 lugares citando los montos viejos: las paginas de indice y compras
    de las tres fases, los gates, la FAQ, el plan maestro, la linea de validacion y
    "antes de gastar un peso". Es la misma clase de desfase que motivo rehacer el
    BOM, asi que se corrige de raiz en vez de dejarlo para despues.
    gen_bom.py calcula ahora tambien la version austera, cambiando cada partida a
    su opcion marcada alternativa_austera. Antes era una frase suelta en las notas
    del CSV que nadie recalculaba, y por eso afirmaba cosas imposibles: que la
    version austera compra "rabano/betabel 250 g" cuando el escalon de precio hace
    que 250 g cu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
2026-09-19 Agregar el tablero de seguimiento del proyecto
    La wiki dice que hacer; no habia donde registrar que llevas hecho. Esta pagina
    (docs/seguimiento.md) es la libreta: compras con el precio REAL pagado contra el
    del plan, estado de los tres gates calculado contra su umbral, y las once
    validaciones V1-V11.
    No duplica datos. tools/gen_seguimiento.py genera el JSON del tablero desde
    bom/partidas.csv y desde los umbrales escritos en docs/validacion/gates.md, asi
    que si cambia el BOM el tablero cambia solo. Es el mismo principio que hizo
    falta para arreglar el BOM: una sola fuente de verdad y todo lo demas derivado.
    Lo que guarda vive en localStorage del navegador. Eso tiene un costo real y la
    pagin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
2026-09-19 Agregar la opcion de comprar en linea, con selector y envios consolidados
    La duda de origen: "si compro en muchas paginas voy a pagar muchos costos de
    envio". Se investigo con fuentes y la respuesta tiene dos partes.
    La primera es el mecanismo. En Mercado Libre, los productos FULL de vendedores
    DISTINTOS salen de la misma bodega y llegan en UN SOLO paquete, gratis si el
    carrito pasa $299. Sin Full no hay consolidacion entre vendedores: se paga un
    envio por cada uno. De ahi la regla practica que ahora esta escrita en la wiki:
    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
    [envios.csv, fase0.csv, fase1.csv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]
